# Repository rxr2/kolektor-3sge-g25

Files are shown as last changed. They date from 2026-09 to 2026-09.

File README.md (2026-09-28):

# Kolektor 3S-GE BEAMS → Garrett G25-550 (top-mount)

Interaktywny podgląd 3D spawanego kolektora wydechowego top-mount dla Toyoty 3S-GE BEAMS pod turbo Garrett G25-550 0.72 V-band (wersja końcowa v15).

**Podgląd online:** https://rxr2.github.io/kolektor-3sge-g25/

## Co zawiera

- model kolektora v15: kołnierz i wyloty OEM, kolana 44,5×2,6 (2d R40 / 5d R97,5), merge 4w1 z końców kolan (zbieg 22°) bez stożka – kolce wchodzą wprost w kołnierz V-band, przegroda 1+4 | 2+3,
- model głowicy i bloku 3S-GE (przylgi z pomiaru uszczelek, bryła z fotogrametrii),
- G25-550 ze skanu 3D z przybliżonym siłownikiem IWG,
- linie spawów (16 spoin, ok. 2,2 m),
- [szablony do druku 1:1 (PDF)](szablony_v15.pdf) – paski owijane na kolanach z liniami cięcia i kolcami merge, przegroda,
- [model STEP kolektora](kolektor_g25_v15.step),
- animację przepływu spalin z symulacji 1D (4500 i 7500 obr/min, kolejność zapłonu 1-3-4-2) z wykresem ciśnienia w portach.

## Obsługa

Przeciągnij – obrót, kółko – zoom, prawy przycisk – przesuwanie. Przyciski na górze przełączają widoki i warstwy; **Przepływ ▶** uruchamia animację (panel można zwinąć).

## Zastrzeżenia

Symulacja 1D służy do porównań wariantów, nie do przewidywania mocy (stałe doładowanie, turbina jako dysza, założone wałki 248°/248°). Tory cząstek w zbiegu i ślimaku są poglądowe. Siłownik IWG jest przybliżony.

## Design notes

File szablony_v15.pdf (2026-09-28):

## Kolektor 3S-GE → G25 v15 – szablony do cięcia 1:1

100 mm – sprawdź linijką (druk 100 %, bez „dopasuj do strony”)

Rura / kolana: 44.5 × 2.6 (EN 10253: 2d R40, 5d R97,5). Obwód zewnętrzny 139.8 mm.

Jak używać:

1. Wydrukuj w skali 100 %, sprawdź czerwoną podziałkę 100 mm.
2. Wytnij pasek wzdłuż ramki (z zakładką), owiń na rurze/kolanie, skleić na zakładce.
3. Niebieska linia = linia odniesienia (czoło kolana lub spoina) – ustaw ją równo z tym miejscem.
4. Linia 0° (grzbiet, EXTRADOS) = zewnętrzna, najdłuższa strona łuku. Pionowe znaczniki pokazują

stronę głowicy / turbo, żeby nie odwrócić szablonu. Kierunek φ: patrząc z góry na szablon.

5. Zaznacz linię cięcia rysikiem, tnij piłą, dopasuj pilnikiem do sąsiedniej rury.

Kolejność budowy: wyloty OEM ucięte 25 mm za kołnierzem → kolano 1 → (krótki prosty) → kolano 2 z wyciętym

kolcem → sczepić 4 kolce w przyrządzie z kołnierzem V-band → przegroda → spawanie z formowaniem.

C i D to lustrzane odbicia B i A – mają własne szablony (nie odwracaj kartki).

## Runner A (cyl. 1) – KOLANO 1: 5d R97,5 przyciąć do 71.2°

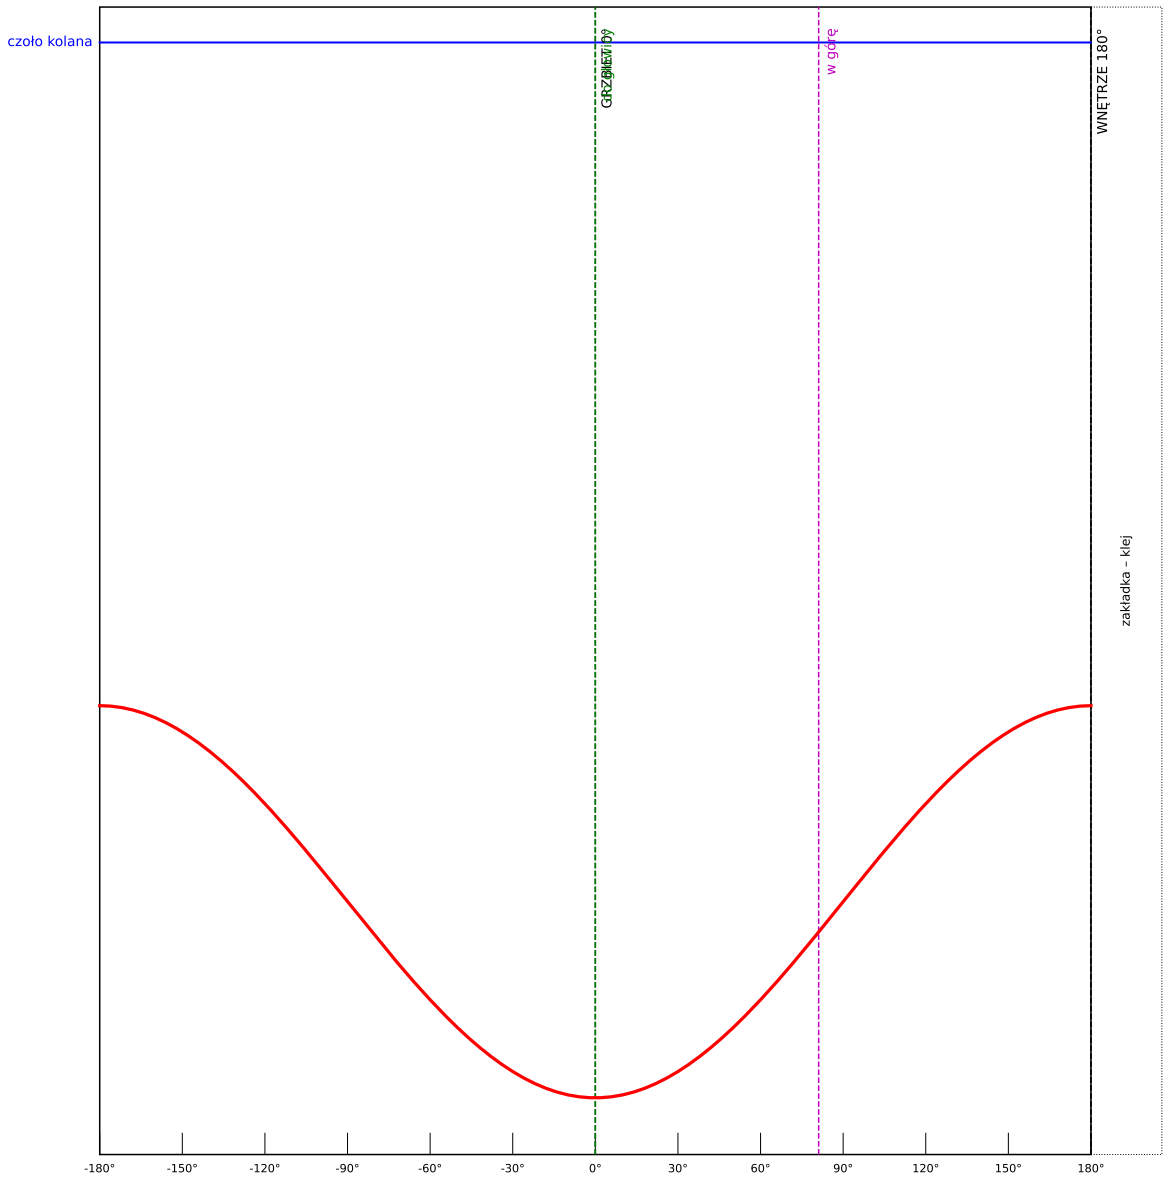
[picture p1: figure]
czoło kolana; 180° GRZBIET 0°; WNĘdo g; TRZE 180°; łowicy; w górę

100 mm – sprawdź linijką (druk 100 %, bez „dopasuj do strony”) zakładka ⁻ klej

Linia odniesienia = czoło kolana 90° od strony WLOTU (od głowicy). Czerwona linia = cięcie; zostaje część powyżej niebieskiej linii do czerwonej.

Długość łuku: grzbiet 148.9 mm, oś 121.2 mm, wnętrze 93.6 mm.

Znaczniki zielony/fioletowy dotyczą ustawienia kolana w kolektorze (po przyspawaniu do wylotu OEM).

## Runner A (cyl. 1) – KOLANO 2: 2d R40 88.5° + KOLEC

# 100 mm – sprawdź linijką (druk 100 %, bez „dopasuj do strony”) zakładka ⁻ klej

czoło WLOTU kolana
-180° | -150° | -120° | -90° | -60° | -30° | 0° | 30° | 60° | 90° | 120° | 150° | 180° GRZBIET | grzbiet kolana 1
a) Od strony WLOTU kolana 90° odetnij 1.5° (czerwona linia). Wylot kolana zostaje nietknięty – od niego liczony jest kolec.

Niebieski znacznik: tu ma wypaść grzbiet kolana 1 przy spawaniu (obrót między kolanami).

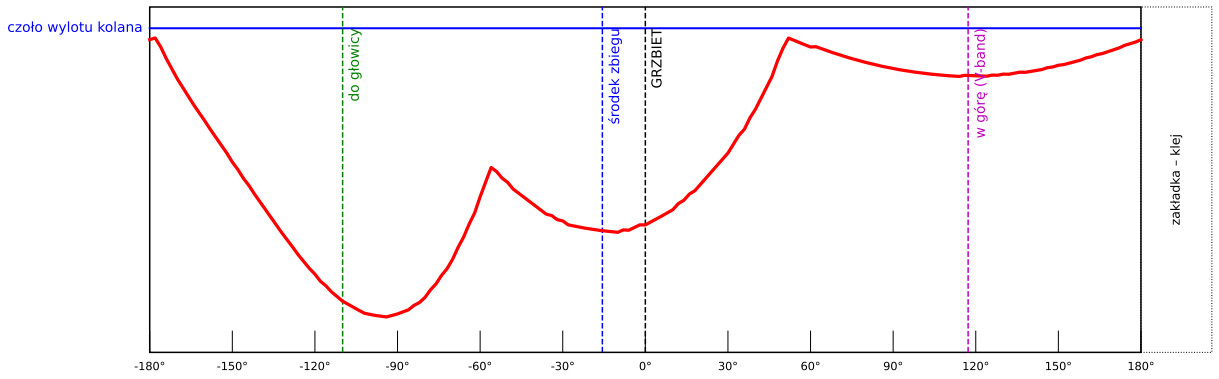
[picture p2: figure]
zakładka – klej; czoło wylotu kolana; 180° GRZBIET do głowicy; w górę ⁽V⁻band⁾; środek zbiegu

b) Niebieska linia = CZOŁO WYLOTU kolana (bez przycinania). Owiń szablon tak, by niebieska linia leżała równo z czołem;

cały kolec mieści się na kolanie – odcinek prosty nie jest potrzebny.

c) Wytnij wzdłuż czerwonej linii – to kolec merge (płaszczyzna środkowa + dopasowanie do rur drugiej pary

+ płaszczyzna kołnierza V-band). Dopasuj na sucho do pozostałych 3 kolców w przyrządzie przed spawaniem.

## Runner B (cyl. 2) – KOLANO 1: 2d R40 przyciąć do 27.6°

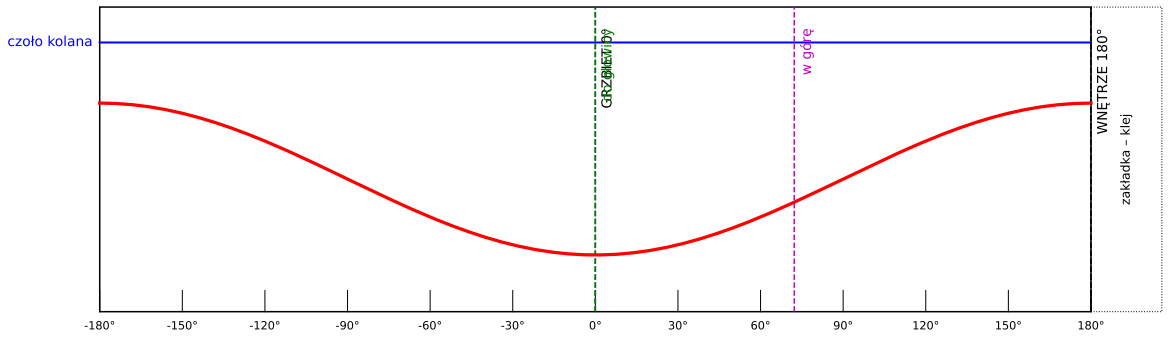
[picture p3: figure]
czoło kolana; 180° GRZBIET 0°; WNĘdo g; TRZE 180°; łowicy; w górę

# 100 mm – sprawdź linijką (druk 100 %, bez „dopasuj do strony”) zakładka ⁻ klej

Linia odniesienia = czoło kolana 90° od strony WLOTU (od głowicy). Czerwona linia = cięcie; zostaje część powyżej niebieskiej linii do czerwonej.

Długość łuku: grzbiet 30.0 mm, oś 19.3 mm, wnętrze 8.5 mm.

Znaczniki zielony/fioletowy dotyczą ustawienia kolana w kolektorze (po przyspawaniu do wylotu OEM).

## Runner B (cyl. 2) – KOLANO 2: 2d R40 77.2° + KOLEC

# 100 mm – sprawdź linijką (druk 100 %, bez „dopasuj do strony”) zakładka ⁻ klej

czoło WLOTU kolana
-180° | -150° | -120° | -90° | -60° | -30° | 0° | 30° | 60° | 90° | 120° | 150° | 180° GRZBIET | grzbiet kolana 1
a) Od strony WLOTU kolana 90° odetnij 12.8° (czerwona linia). Wylot kolana zostaje nietknięty – od niego liczony jest kolec.

Niebieski znacznik: tu ma wypaść grzbiet kolana 1 przy spawaniu (obrót między kolanami).

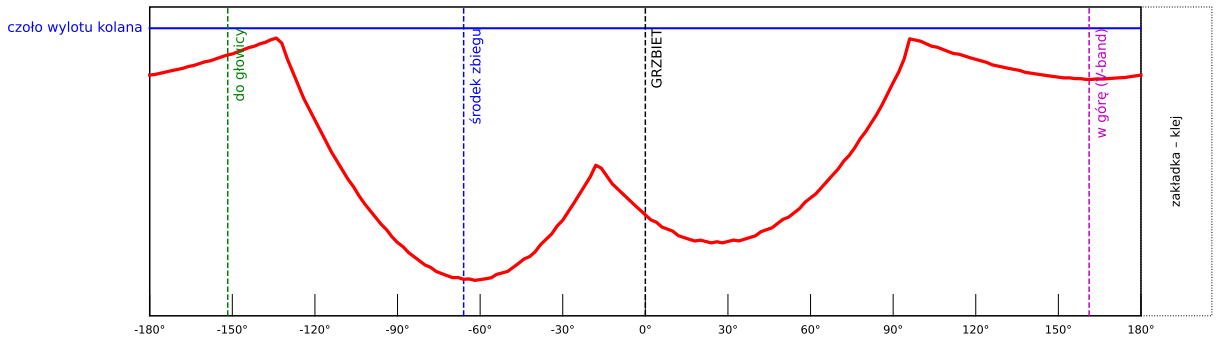
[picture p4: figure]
zakładka – klej; czoło wylotu kolana; 180° GRZBIET do głowicy; w górę ⁽V⁻band⁾; środek zbiegu

b) Niebieska linia = CZOŁO WYLOTU kolana (bez przycinania). Owiń szablon tak, by niebieska linia leżała równo z czołem;

cały kolec mieści się na kolanie – odcinek prosty nie jest potrzebny.

c) Wytnij wzdłuż czerwonej linii – to kolec merge (płaszczyzna środkowa + dopasowanie do rur drugiej pary

+ płaszczyzna kołnierza V-band). Dopasuj na sucho do pozostałych 3 kolców w przyrządzie przed spawaniem.

## Runner C (cyl. 3) – KOLANO 1: 2d R40 przyciąć do 27.6°

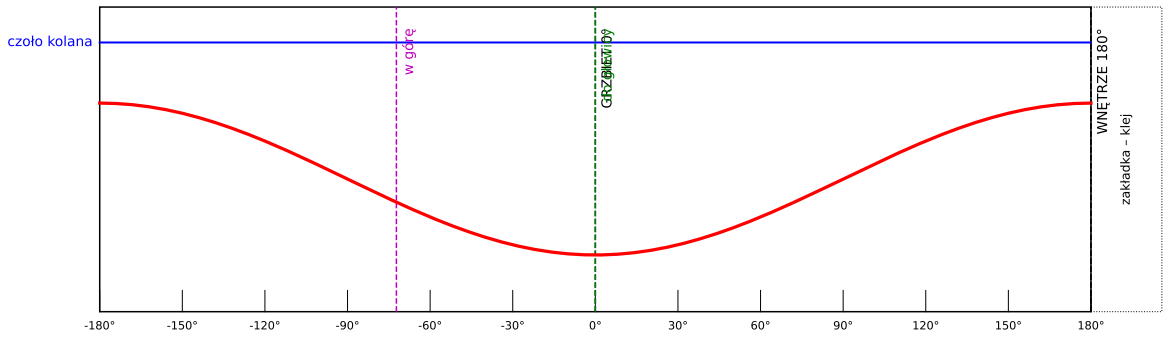
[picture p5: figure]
czoło kolana; 180° GRZBIET 0°; WNĘdo g; TRZE 180°; łowicy; w górę

# 100 mm – sprawdź linijką (druk 100 %, bez „dopasuj do strony”) zakładka ⁻ klej

Linia odniesienia = czoło kolana 90° od strony WLOTU (od głowicy). Czerwona linia = cięcie; zostaje część powyżej niebieskiej linii do czerwonej.

Długość łuku: grzbiet 30.0 mm, oś 19.3 mm, wnętrze 8.5 mm.

Znaczniki zielony/fioletowy dotyczą ustawienia kolana w kolektorze (po przyspawaniu do wylotu OEM).

## Runner C (cyl. 3) – KOLANO 2: 2d R40 77.2° + KOLEC

# 100 mm – sprawdź linijką (druk 100 %, bez „dopasuj do strony”) zakładka ⁻ klej

czoło WLOTU kolana
-180° | -150° | -120° | -90° | -60° | -30° | 0° | 30° | 60° | 90° | 120° | 150° | 180° GRZBIET grzbiet kolana 1
a) Od strony WLOTU kolana 90° odetnij 12.8° (czerwona linia). Wylot kolana zostaje nietknięty – od niego liczony jest kolec.

Niebieski znacznik: tu ma wypaść grzbiet kolana 1 przy spawaniu (obrót między kolanami).

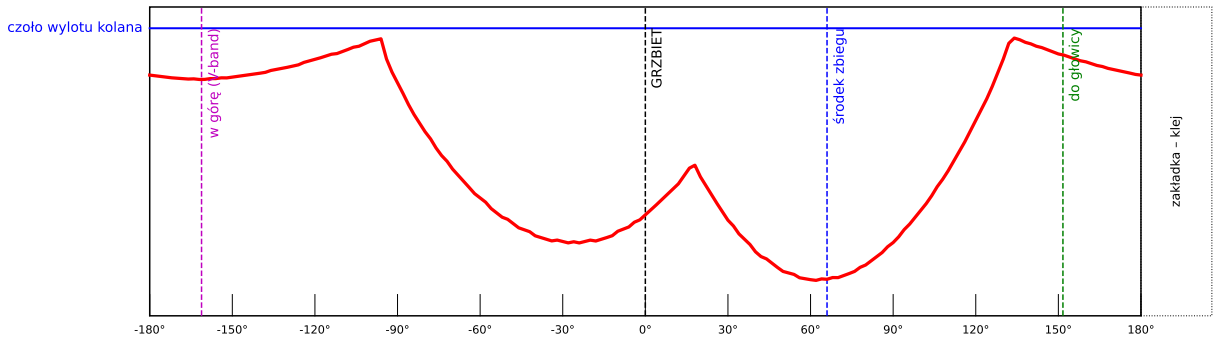
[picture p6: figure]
zakładka – klej; czoło wylotu kolana; 180° GRZBIET; do głowicy w górę ⁽V⁻band⁾; środek zbiegu

b) Niebieska linia = CZOŁO WYLOTU kolana (bez przycinania). Owiń szablon tak, by niebieska linia leżała równo z czołem;

cały kolec mieści się na kolanie – odcinek prosty nie jest potrzebny.

c) Wytnij wzdłuż czerwonej linii – to kolec merge (płaszczyzna środkowa + dopasowanie do rur drugiej pary

+ płaszczyzna kołnierza V-band). Dopasuj na sucho do pozostałych 3 kolców w przyrządzie przed spawaniem.

## Runner D (cyl. 4) – KOLANO 1: 5d R97,5 przyciąć do 71.2°

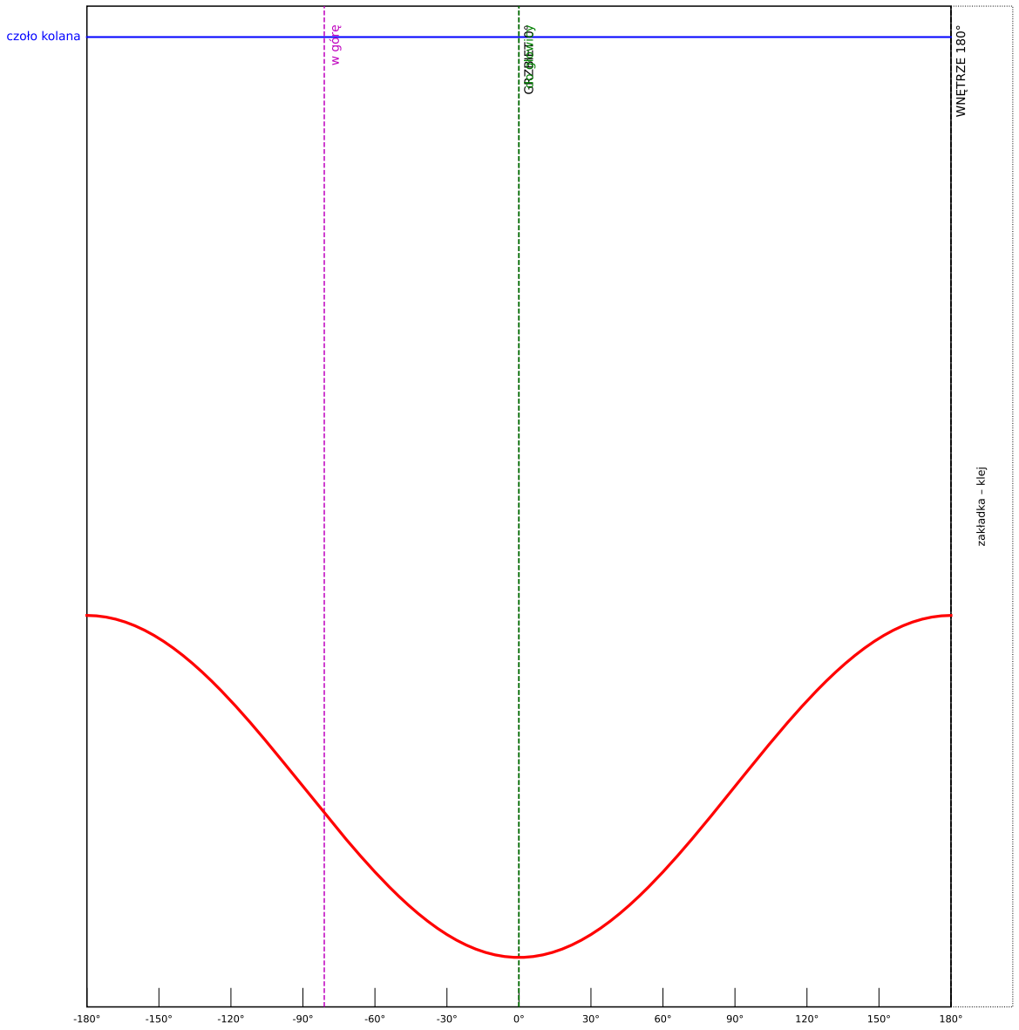
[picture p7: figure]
czoło kolana; 180° GRZBIET 0°; WNĘdo g; TRZE 180°; łowicy; w górę

100 mm – sprawdź linijką (druk 100 %, bez „dopasuj do strony”) zakładka ⁻ klej

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

Długość łuku: grzbiet 148.9 mm, oś 121.2 mm, wnętrze 93.6 mm.

Znaczniki zielony/fioletowy dotyczą ustawienia kolana w kolektorze (po przyspawaniu do wylotu OEM).

## Runner D (cyl. 4) – KOLANO 2: 2d R40 88.5° + KOLEC

# 100 mm – sprawdź linijką (druk 100 %, bez „dopasuj do strony”) zakładka ⁻ klej

czoło WLOTU kolana
-180° | -150° | -120° | -90° | -60° | -30° | 0° | 30° | 60° | 90° | 120° | 150° | 180° GRZBIET grzbiet kolana 1
a) Od strony WLOTU kolana 90° odetnij 1.5° (czerwona linia). Wylot kolana zostaje nietknięty – od niego liczony jest kolec.

Niebieski znacznik: tu ma wypaść grzbiet kolana 1 przy spawaniu (obrót między kolanami).

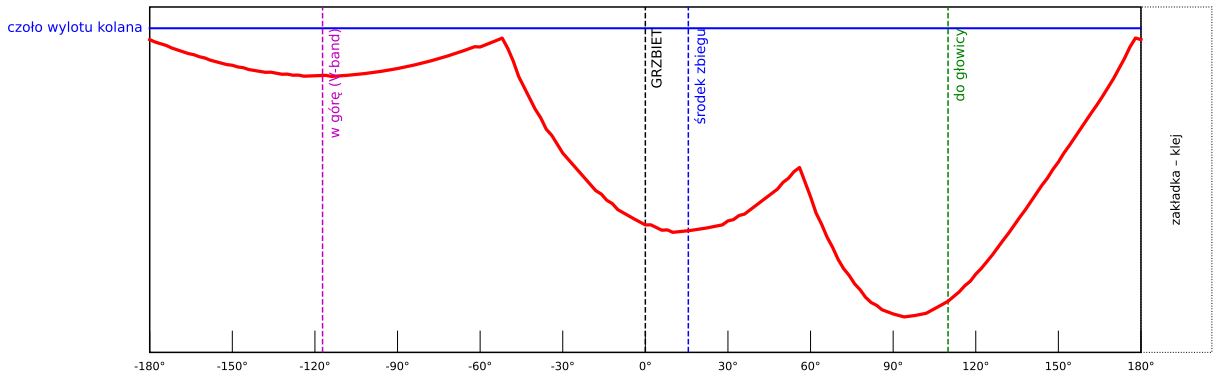
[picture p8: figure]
zakładka – klej; czoło wylotu kolana; 180° GRZBIET; do głowicy w górę ⁽V⁻band⁾; środek zbiegu

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

cały kolec mieści się na kolanie – odcinek prosty nie jest potrzebny.

c) Wytnij wzdłuż czerwonej linii – to kolec merge (płaszczyzna środkowa + dopasowanie do rur drugiej pary

+ płaszczyzna kołnierza V-band). Dopasuj na sucho do pozostałych 3 kolców w przyrządzie przed spawaniem.

## PRZEGRODA 3 mm (Inconel 625 / 310S / 321) – 1:1, przegroda_v15.dxf

100 mm – sprawdź linijką (druk 100 %, bez „dopasuj do strony”)

Wymiar: 59.9 (wzdłuż głowicy) × 41.5 mm (pion). Góra rysunku = strona kołnierza V-band.

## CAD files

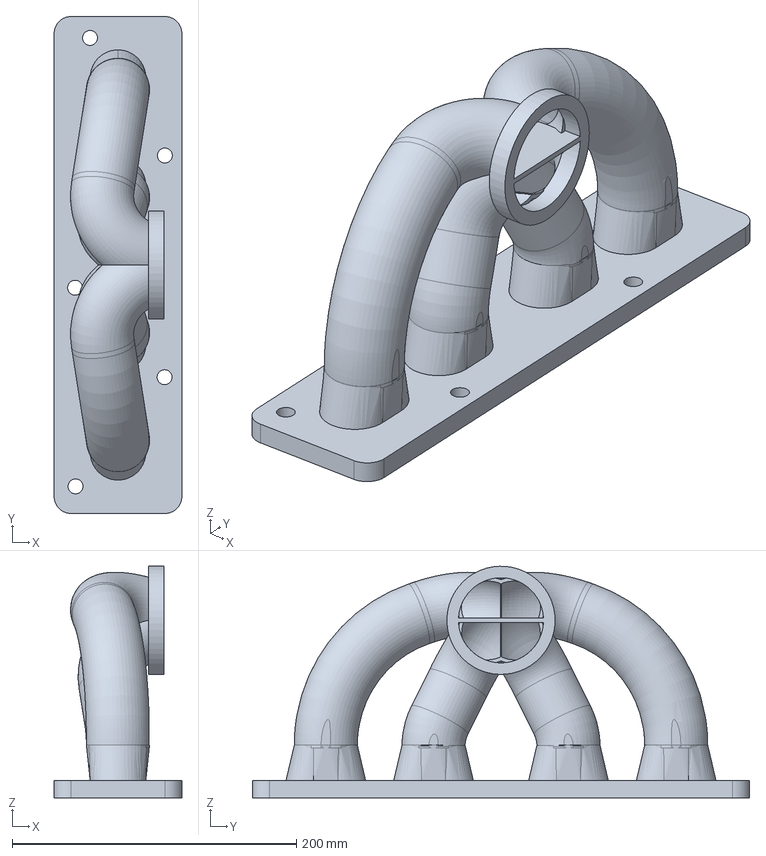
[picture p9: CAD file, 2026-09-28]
kolektor_g25_v15.step
90.0 x 350.0 x 163.1 mm

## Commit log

2026-09-28 Wersja końcowa v15 (bez stożka) + szablony do druku 1:1 i model STEP
    [kolektor_g25_v15.step]
2026-09-28 Dolot: kolektor ssący B48 na adapterze 45° + STEP adaptera
    [adapter_b48_3sge.step]
2026-09-28 Adapter B48 do druku 3D (grubość 41,7 mm, tulejki stalowe, dostęp do śrub głowicy)
    [adapter_b48_3sge.step, adapter_b48_druk3d.step, adapter_b48_druk3d.stl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]
2026-09-28 Adapter B48 dwuczęściowy (dostęp do śrub głowicy), kolektor B48 obrócony (przepustnica z przodu), wylot sprężarki w dół
    [adapter_b48_czesc_A.step, adapter_b48_czesc_A.stl, adapter_b48_czesc_B.step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]
2026-09-28 Usunięty kolektor ssący B48 i adapter (wystawał ponad silnik)
    [adapter_b48_czesc_A.step, adapter_b48_czesc_A.stl, adapter_b48_czesc_B.step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]
